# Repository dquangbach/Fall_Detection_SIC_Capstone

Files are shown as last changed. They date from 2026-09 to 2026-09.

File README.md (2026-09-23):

# Fall Detection — CNN-LSTM & Leave-One-Subject-Out

Dự án phát hiện té ngã từ gia tốc ba trục, sử dụng **CNN-LSTM** và đánh giá khả năng tổng quát hóa sang người chưa xuất hiện trong tập train bằng **Leave-One-Subject-Out (LOSO)** trên **32 subject K-Fall**.

Pipeline chính nằm trong [model_cnn_lstm_loso.ipynb](model_cnn_lstm_loso.ipynb): đọc nhãn K-Fall, tạo cửa sổ, huấn luyện và đánh giá 32 fold, sau đó train model cuối trên dữ liệu của cả 32 subject. [model_cnn_lstm.ipynb](model_cnn_lstm.ipynb) là thử nghiệm đối chứng với split cố định và **không augmentation**; không phải nguồn kết quả LOSO.

Repository còn có thiết kế PCB, phần firmware ESP32-S3/MPU6050 và receiver Polar H10 phục vụ thử nghiệm. Model CNN-LSTM Keras hiện tại và model nhúng trong firmware là các bộ artifact khác nhau.

## Cấu trúc dự án

```text
.
├── model_cnn_lstm_loso.ipynb     # Pipeline chính: LOSO + train model cuối
├── model_cnn_lstm.ipynb          # Đối chứng: split subject cố định, no augmentation
├── saved_models_cnn_lstm/
│   ├── best_model_SAxx.keras    # Checkpoint của fold có SAxx làm test
│   ├── final_selection_best.keras
│   ├── final_model.keras       # Model train lại trên toàn bộ 32 subject
│   ├── scaler.pkl              # Scaler đi cùng final_model.keras
│   ├── metadata.pkl            # Features, window, threshold, thông tin train cuối
│   ├── best_model_noaug.keras  # Checkpoint thử nghiệm no augmentation
│   └── best_model.keras        # Checkpoint thử nghiệm trước đó
├── kfall/
│   ├── label_data_new/         # Nhãn onset/impact: SAxx_label.xlsx
│   └── sensor_data_new/        # CSV theo subject, chuẩn bị riêng ở máy local
├── polar_h10_receiver/         # Thử nghiệm inference Python từ UDP Polar H10
├── esp32s3-tinyml-fall-detector/ # Repository firmware được ghi nhận bằng gitlink
├── fall_detection_pcb/         # Schematic, PCB, footprint KiCad và PDF
├── fall_detection_dataset/     # Dữ liệu local của pipeline cũ
└── doc/                        # Tài liệu tham khảo local
```

Các notebook cũ như `model.ipynb` và `model_3_features.ipynb` không còn trong cây dự án hiện tại. Bắt đầu với **`model_cnn_lstm_loso.ipynb`**.

## Dữ liệu và nhãn

Notebook chính đọc trực tiếp:

```text
kfall/
├── label_data_new/
│   ├── SA06_label.xlsx
│   └── ...
└── sensor_data_new/
    ├── SA06/
    │   ├── S06T01R01.csv
    │   └── ...
    └── ...
```

- Danh sách subject được lấy từ các thư mục bắt đầu bằng `SA` trong `sensor_data_new`.
- Tên CSV theo mẫu `SxxTxxRxx.csv`, chứa subject, task và trial.
- CSV cần các cột `FrameCounter`, `AccX`, `AccY`, `AccZ`. Dữ liệu được dùng theo thứ tự dòng có sẵn trong file; cần giữ thứ tự thời gian.
- File Excel nhãn sử dụng `Task Code (Task ID)`, `Trial ID`, `Fall_onset_frame`, `Fall_impact_frame`.
- Nhãn mẫu là ngã nếu `onset <= FrameCounter <= impact`. Recording không có trong bảng nhãn được xem là bình thường; cần chuẩn bị đầy đủ các file nhãn để tránh gán sai.
- Pipeline này không cần cột `FallCheck` và không đọc từ `Sample_Training/Sample_Test` của pipeline cũ.

Dữ liệu gia tốc dùng đơn vị **g**, với bước thời gian 0.01 giây (100 Hz) trong CSV K-Fall hiện có. Notebook không tự resample hoặc chuyển đơn vị.

### Cửa sổ và chuẩn hóa

| Thiết lập | Giá trị |
|---|---|
| Features theo thứ tự | `AccX, AccY, AccZ` |
| Window size | 200 mẫu, khoảng 2 giây ở 100 Hz |
| Window step | 100 mẫu, overlap 50% |
| Nhãn cửa sổ | Fall nếu ít nhất 20% mẫu nằm trong khoảng onset–impact |
| Input model | `(batch, 200, 3)`, không flatten |
| Output | Một sigmoid score cho lớp Fall |
| Decision threshold | `score >= 0.50` → Fall |

Cửa sổ được tạo riêng trong từng recording; không nối hai recording hoặc hai subject. Đoạn cuối thiếu 200 mẫu bị bỏ qua. Cửa sổ từng subject được cache trong RAM để tái sử dụng qua các fold.

Trong mỗi fold, `StandardScaler` được fit **chỉ trên cửa sổ train gốc**, theo từng feature bằng `reshape(-1, 3)`. Scaler đó transform train, train augmentation, validation và test. Không fit scaler trên subject test.

### Augmentation của pipeline chính

Chỉ áp dụng lên tập train, trước chuẩn hóa:

| Phép biến đổi | Xác suất trên mỗi bản sao cửa sổ | Cấu hình |
|---|---:|---|
| Jitter | 0.10 | Nhiễu Gaussian, mean 0, sigma 0.05 |
| Scaling | 0.10 | Một hệ số chung cho Acc XYZ, Gaussian mean 1, sigma 0.10 |
| Rotation | 0.10 | Góc ngẫu nhiên ±10° mỗi trục, cùng phép quay cho toàn bộ cửa sổ |

Ba phép được chọn độc lập nên một cửa sổ có thể nhận nhiều phép hoặc không nhận phép nào. Ghép tập gốc với tập bản sao để tăng gấp đôi số window train; nhãn giữ nguyên. Validation/test của LOSO không augmentation.

## Kiến trúc CNN-LSTM

```text
Input (200, 3)
  → Conv1D(32, kernel=5, same) → BatchNorm → ReLU → MaxPool(2) → Dropout(0.2)
  → Conv1D(64, kernel=3, same) → BatchNorm → ReLU → MaxPool(2) → Dropout(0.2)
  → LSTM(64, dropout=0.2, recurrent_dropout=0)
  → Dense(32, ReLU) → Dropout(0.3)
  → Dense(1, sigmoid)
```

CNN trích đặc trưng cục bộ theo thời gian; LSTM xử lý chuỗi đặc trưng sau hai bước pooling. Loss là `binary_crossentropy`; optimizer Adam bắt đầu tại learning rate `1e-3`. Class weight được tính theo `N / (2 × N_class)` để cân bằng hai lớp.

## Đánh giá Leave-One-Subject-Out

Với 32 subject, notebook chạy 32 fold. Trong mỗi fold:

1. Giữ 1 subject làm **test độc lập**.
2. Chọn xoay vòng 2 subject trong 31 subject còn lại làm validation.
3. Dùng 29 subject còn lại để train, augmentation và fit scaler.
4. Khởi tạo CNN-LSTM mới, chọn checkpoint theo validation.
5. Nạp checkpoint tốt nhất và dự đoán subject test tại threshold cố định 0.50.

Mỗi subject làm test đúng một lần. Đây là LOSO có validation tách theo subject, không phải chia ngẫu nhiên window và cũng không phải nested LOSO để tìm hyperparameter.

### Cấu hình huấn luyện mỗi fold

| Thiết lập | Giá trị trong code |
|---|---|
| Batch size | 32 |
| Epoch tối đa | 50 |
| ModelCheckpoint | `val_recall`, `mode="max"`, lưu best |
| EarlyStopping | `val_recall`, patience 12, min_delta `1e-3`, restore best weights |
| ReduceLROnPlateau | `val_loss`, patience 3, factor 0.5, min_lr `1e-5` |
| Threshold test | 0.50, không quét ngưỡng trên test |

Checkpoint lưu thành `saved_models_cnn_lstm/best_model_<test_subject>.keras`. Test dùng checkpoint tải lại; `ModelCheckpoint` không đặt `min_delta` như `EarlyStopping`, nên hai callback có thể chọn epoch khác nhau.

### Báo cáo kết quả

Cell tổng hợp tạo:

- Bảng mỗi fold: số window, phân bố lớp, Accuracy, Precision/Recall/F1/F2 lớp Fall, ROC-AUC và TN/FP/FN/TP.
- Mean, standard deviation, min và max qua các fold. ROC-AUC là NaN nếu test fold chỉ có một lớp.
- Confusion matrix và classification report gộp dự đoán của toàn bộ subject test.
- Biểu đồ Precision và Recall theo subject.

Mean qua subject và metrics gộp theo window là hai cách tổng hợp khác nhau. Các chỉ số ở đây đánh giá **cửa sổ**, không tự tương đương số sự kiện ngã phát hiện được hoặc số cảnh báo giả mỗi giờ.

**Tình trạng kết quả trong repository:** có 32 checkpoint theo subject, nhưng notebook LOSO hiện lưu với output rỗng và chưa có bảng metrics LOSO được export. Vì vậy README không gán số đo từ notebook đối chứng hay validation của model cuối cho LOSO. Để công bố kết quả, lưu output cell tổng hợp và bảng từng fold sau lần chạy tương ứng.

Scalers từng fold và dự đoán test chưa được lưu thành artifact riêng. Cell mục 7 có thể nạp trực tiếp 32 file `best_model_SAxx.keras` và dựng lại scaler từ đúng 29 subject train gốc của mỗi fold, không cần train lại model. Việc này yêu cầu giữ nguyên dataset, nhãn, thứ tự subject, features, window và cách chia fold như khi train checkpoint. `scaler.pkl` hiện có thuộc model cuối; không dùng scaler này để đánh giá checkpoint LOSO.

## Train model cuối trên 32 subject

Cell cuối của notebook chính dùng `FINAL_USE_AUGMENTATION = True`, seed 42 và thực hiện hai pha:

1. **Chọn epoch:** ghép dữ liệu 32 subject, fit scaler trên toàn bộ window gốc, tạo augmentation, chuẩn hóa và shuffle. Giữ 10% window bằng `validation_split=0.10`; train tối đa 100 epoch, với checkpoint/early stopping theo `val_recall` (patience 12) và giảm LR theo `val_loss` (patience 3). Chọn `argmax(val_recall) + 1`.
2. **Train lại toàn bộ:** khởi tạo CNN-LSTM mới và train trên tất cả window gốc + augmentation của 32 subject đến epoch vừa chọn. Pha này không giữ validation, không dùng early stopping hoặc ReduceLROnPlateau; Adam bắt đầu lại tại `1e-3`. Lưu thành `final_model.keras`.

Validation pha 1 là split theo window sau khi augmentation và fit scaler toàn bộ; các window overlap hoặc bản gốc/bản sao có thể nằm hai phía của split. Vì vậy nó chỉ là tín hiệu chọn epoch nội bộ, **không phải đánh giá subject độc lập**. Lịch giảm LR ở pha 1 cũng không được phát lại trong pha train toàn bộ. Chất lượng cần được báo cáo bằng protocol đánh giá phù hợp, không bằng training score của model cuối.

File `metadata.pkl` hiện ghi: **32 subject, augmentation bật, selected_epoch = 13**, `selected_val_recall ≈ 0.996633`. Đây là thông tin pha chọn epoch của lần export, không phải Recall LOSO hay kết quả kiểm thử độc lập của `final_model.keras`.

### Bộ artifact để inference

| File trong `saved_models_cnn_lstm/` | Vai trò |
|---|---|
| `final_model.keras` | CNN-LSTM train lại trên toàn bộ dữ liệu |
| `scaler.pkl` | StandardScaler fit trên window gốc của 32 subject |
| `metadata.pkl` | Feature order, window size/step, threshold, subject và cấu hình train cuối |
| `final_selection_best.keras` | Checkpoint pha chọn epoch; không phải model train lại toàn bộ |
| `best_model_SAxx.keras` | Model fold LOSO có subject SAxx làm test |
| `best_model_noaug.keras` | Checkpoint thử nghiệm đối chứng no augmentation |

Luôn sử dụng `final_model.keras`, `scaler.pkl` và `metadata.pkl` từ cùng lần export. Khi inference, chỉ transform bằng scaler đã lưu; không fit lại scaler, không augmentation.

## Cài đặt và chạy

Từ thư mục gốc repository:

```bash
python3 -m venv .venv
source .venv/bin/activate
python -m pip install tensorflow numpy pandas scikit-learn matplotlib joblib openpyxl jupyterlab
python -m jupyter lab
```

Trên Windows, kích hoạt bằng `.venv\Scripts\activate`. Chưa có file khóa dependency Python trong repository; cần lưu phiên bản môi trường cho các lần chạy cần tái lập.

1. Chuẩn bị đầy đủ CSV và Excel nhãn theo cấu trúc `kfall/` ở trên.
2. Mở `model_cnn_lstm_loso.ipynb`, chọn kernel đúng môi trường, chạy với working directory là gốc repository.
3. Chạy các cell import, đọc nhãn, cấu hình, cache dữ liệu, augmentation và định nghĩa model.
4. Nếu đã có 32 checkpoint, chạy thẳng **mục 7** để nạp model và đánh giá; chỉ cần import và các mục 1–3, bỏ qua mục 6. Nếu cần train lại, chạy mục 6 trước. Lưu notebook cùng output khi cần báo cáo.
5. Sau khi chốt cách đánh giá, chạy cell cuối để tạo model cho toàn bộ 32 subject.

Nếu chỉ cần train model cuối sau khi đã hoàn tất LOSO, có thể chạy các cell chuẩn bị ở bước 3 rồi chuyển thẳng đến cell cuối; không bắt buộc chạy lại 32 fold. Chạy lại sẽ ghi đè các artifact cùng tên trong `saved_models_cnn_lstm/`; sao lưu bộ cần giữ trước khi thực hiện.

LOSO hiện không đặt seed riêng cho từng fold, trong khi cell final đặt seed 42. Các lần chạy LOSO có thể khác nhau do khởi tạo trọng số, dropout và augmentation ngẫu nhiên.

### Notebook đối chứng

`model_cnn_lstm.ipynb` giữ 6 subject test cố định:
`SA21, SA23, SA24, SA26, SA30, SA33`; chia 26 subject còn lại thành 21 train và 5 validation. Cấu hình hiện tại không augmentation, tối đa 100 epoch, early stopping patience 12 và LR patience 3. Kết quả của notebook này phục vụ đối chiếu, không thay thế đánh giá LOSO.

## Thử nghiệm trực tiếp với Polar H10

Khi có thư mục `polar_h10_receiver/`, chạy trong môi trường đã cài dependencies:

```bash
python polar_h10_receiver/udp_acc_receiver.py --check-model
python polar_h10_receiver/udp_acc_receiver.py
```

Sender gửi UDP đến IP máy tính, port **5005**, theo `timestamp,x_mg,y_mg,z_mg`, với tốc độ đã cấu hình **100 mẫu/giây**. Receiver:

- Đổi mg → g và đổi trục thành `(Polar Y, -Polar X, -Polar Z)`.
- Gom window 200 mẫu, dự đoán lại mỗi 100 mẫu, dùng bộ artifact final.
- In sigmoid score và nhãn tại threshold trong metadata.
- Bỏ mẫu lỗi/trùng/đảo timestamp; reset sau 2 giây không nhận mẫu hợp lệ.

Mặc định đếm frame ở 100 Hz, không resample. Khi biết đơn vị timestamp, có thể thêm `--timestamp-unit ns` (hoặc `us/ms`) để kiểm tra nhịp lấy mẫu và khoảng mất mẫu. Thêm `--show-acc` để xem gia tốc.

Mapping trục giữ từ thử nghiệm receiver; hướng gắn cảm biến, dấu trục Z và khác biệt vị trí đo so với K-Fall cần được xác nhận thực nghiệm. Kết quả LOSO trên K-Fall không tự đại diện cho chất lượng nhận diện trực tiếp trên Polar.

## Phần cứng và trạng thái triển khai

- `fall_detection_pcb/`: thiết kế KiCad, schematic, PCB, footprint ESP32-S3/header và các PDF lớp mạch.
- `esp32s3-tinyml-fall-detector/`: phần firmware ESP32-S3 + MPU6050, lấy mẫu, preprocessing, TFLite Micro, LED và Wi-Fi/MQTT.

Firmware đang là repository riêng, được repository này tham chiếu bằng gitlink; hiện chưa có `.gitmodules` để tự khởi tạo bằng `git submodule update`. Khi clone mới, cần lấy firmware từ repository riêng và đối chiếu revision được ghi nhận.

Bản firmware local đang có thay đổi chưa commit cho input INT8 6 features `(200 × 6)`, step 50; revision firmware được repository chính tham chiếu vẫn dùng cấu hình 8 features. Cả hai đều khác bộ CNN-LSTM final với input float32 `(1,200,3)`. Chưa có artifact TFLite/C của CNN-LSTM final trong `saved_models_cnn_lstm/`; cần thực hiện export, đồng bộ preprocessing và kiểm tra runtime trước khi triển khai model này lên ESP32-S3.

## Dữ liệu và quản lý repository

CSV và file H5 bị loại theo `.gitignore`; thư mục sensor K-Fall cần chuẩn bị riêng khi clone. Các Excel nhãn K-Fall và bộ checkpoint Keras hiện được Git theo dõi. `doc/`, môi trường ảo và cache Python là dữ liệu local.

Thêm một thư mục vào `.gitignore` không tự bỏ tracking các file đã commit. Receiver Polar hiện vẫn có file được Git theo dõi; cần phân biệt tình trạng đó với quy tắc ignore local.

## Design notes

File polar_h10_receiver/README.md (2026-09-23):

# Polar H10 → CNN-LSTM trực tiếp

Chạy từ thư mục `Fall_Detection_SIC_Capstone`, bằng môi trường Python đã dùng train:

```sh
../.venv/bin/python polar_h10_receiver/udp_acc_receiver.py
```

Sender gửi UDP đến IP máy tính, port **5005**, mỗi mẫu theo định dạng
`timestamp,x_mg,y_mg,z_mg`. Một datagram có thể chứa nhiều dòng mẫu.
Timestamp phải tăng theo từng mẫu cảm biến; không dùng chung timestamp của một
batch cho tất cả mẫu. Sender nên giữ cùng socket/cổng nguồn trong phiên streaming.

Receiver mặc định dùng **100 frame/giây** theo cấu hình Polar được xác nhận.
Nó tự đọc `final_model.keras`, `scaler.pkl`, `metadata.pkl` trong
`saved_models_cnn_lstm/` (đường dẫn tính từ file script, không phụ thuộc cwd).
Các thư viện cần có trong môi trường: TensorFlow, NumPy, scikit-learn, joblib.

Pipeline: đổi mg → g → đổi trục `(X,Y,Z) = (Polar Y,-Polar X,-Polar Z)` →
gom 200 mẫu → transform bằng scaler đã xuất → tensor `(1,200,3)` → model.
Không fit lại scaler và không augmentation khi dự đoán. `window_size`, `window_step`,
thứ tự feature và threshold lấy từ metadata; hiện là **200 / 100 / 0.50**.
Lần đầu cần khoảng 2 giây dữ liệu, sau đó dự đoán mỗi giây.

Ví dụ định dạng kết quả (số minh họa):

```text
t=123456789 | FALL / NGA | P(fall)=0.8732 | inference=4.5ms
```

Các tùy chọn:

```sh
# Kiểm tra bộ artifact và warm-up inference, không mở UDP
../.venv/bin/python polar_h10_receiver/udp_acc_receiver.py --check-model

# In thêm gia tốc từng mẫu
../.venv/bin/python polar_h10_receiver/udp_acc_receiver.py --show-acc

# Khi đã xác nhận timestamp đơn vị ns (hoặc ms/us), bật kiểm tra gap/cadence
../.venv/bin/python polar_h10_receiver/udp_acc_receiver.py --timestamp-unit ns

# Ghi lại stdout của phiên thử nghiệm
../.venv/bin/python -u polar_h10_receiver/udp_acc_receiver.py | tee polar_session.log
```

Nhấn Ctrl+C để dừng. Mẫu lỗi, timestamp trùng hoặc đảo thứ tự bị bỏ qua. Sau 2 giây
không có mẫu hợp lệ, buffer và sender được reset. Mặc định chưa biết đơn vị timestamp
nên không phát hiện được mọi khoảng mất gói ngắn; dùng `--timestamp-unit` khi đã xác
nhận để reset nếu khoảng cách mẫu lệch quá 20% so với 0.01 giây. Code không resample;
sender phải thực sự chạy 100 Hz. `--timeout` cho phép đổi thời gian reset.

Phép đổi trục được giữ từ receiver cũ, trong đó dấu trục Z còn cần kiểm chứng thực
nghiệm. Vị trí đeo H10 và hướng trục so với cảm biến K-Fall có thể ảnh hưởng kết quả;
metrics LOSO K-Fall không phải kết quả kiểm chứng trên Polar trực tiếp.

Kiểm tra parser, cửa sổ, gap và inference với model thật:

```sh
../.venv/bin/python -m unittest discover -s polar_h10_receiver -v
```

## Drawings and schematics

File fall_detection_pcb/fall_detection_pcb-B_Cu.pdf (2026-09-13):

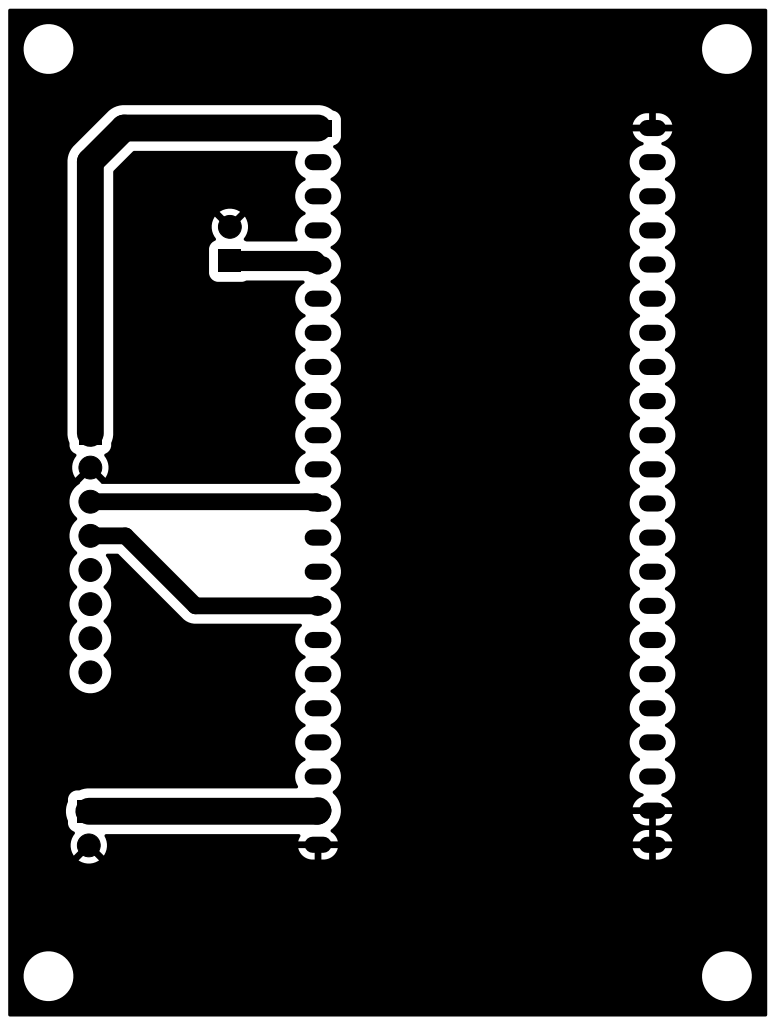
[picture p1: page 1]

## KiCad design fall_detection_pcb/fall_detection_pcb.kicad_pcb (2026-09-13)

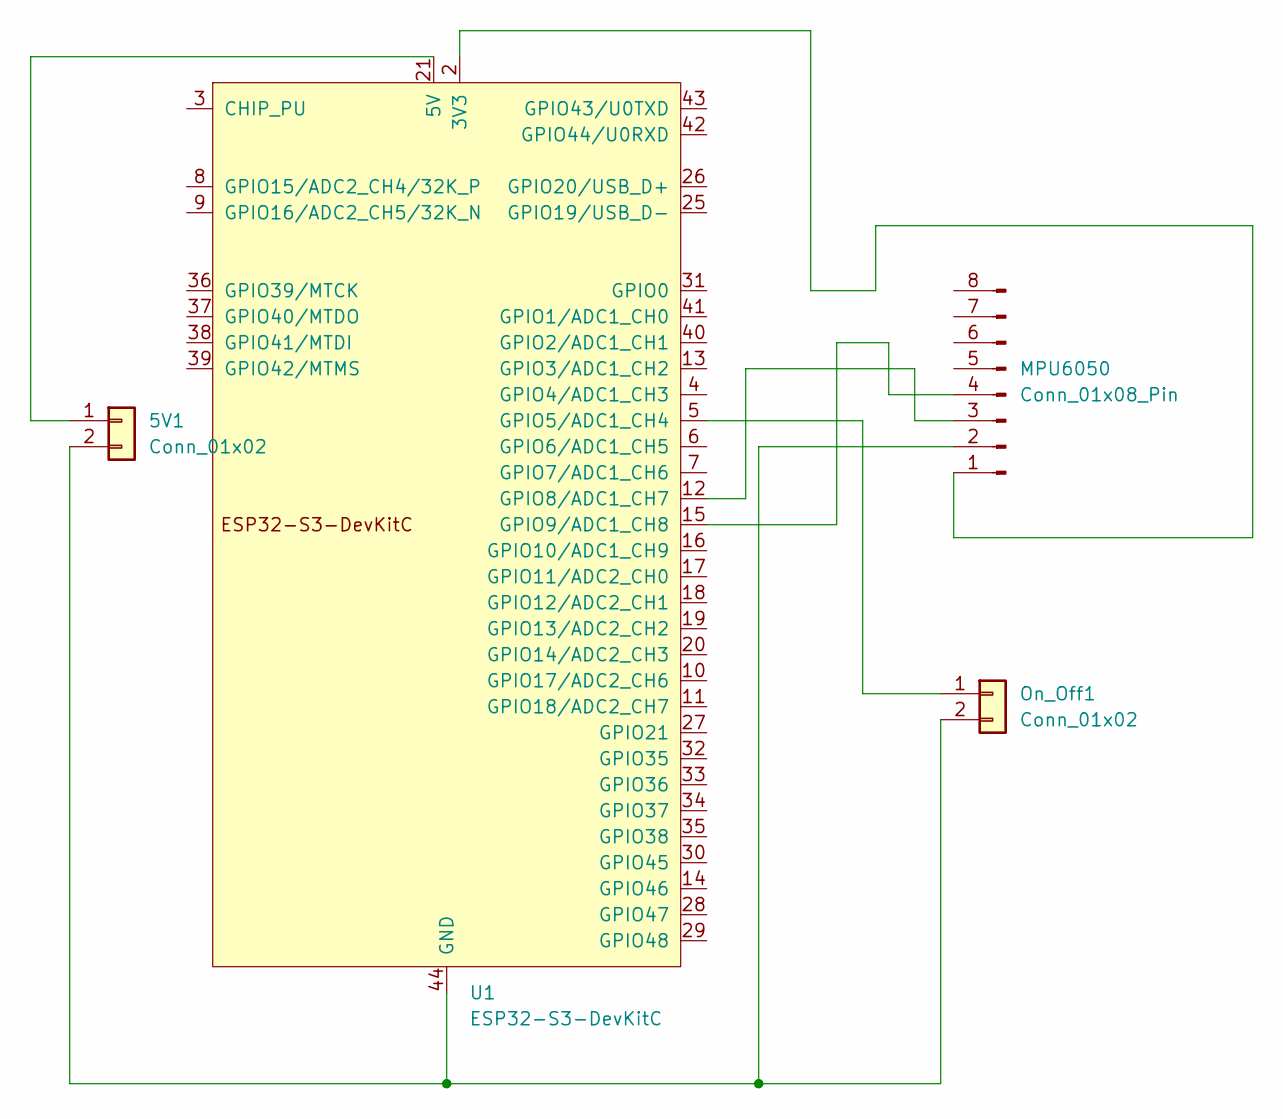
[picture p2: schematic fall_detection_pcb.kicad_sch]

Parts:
5V1: Conn_01x02; PinHeader_1x02_P2.54mm_Vertical
MPU6050: Conn_01x08_Pin; PinHeader_1x08_P2.54mm_Horizontal
On_Off1: Conn_01x02; PinHeader_1x02_P2.54mm_Vertical
U1: ESP32-S3-DevKitC

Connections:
unnamed: 5V1.1, U1.21 (5V)
unnamed: 5V1.2, MPU6050.2, On_Off1.2, U1.22 (GND), U1.23 (GND), U1.24 (GND), U1.44 (GND)
unnamed: MPU6050.1, U1.1 (3V3), U1.2 (3V3)
unnamed: MPU6050.3, U1.12 (GPIO8/ADC1_CH7)
unnamed: MPU6050.4, U1.15 (GPIO9/ADC1_CH8)
unnamed: On_Off1.1, U1.5 (GPIO5/ADC1_CH4)

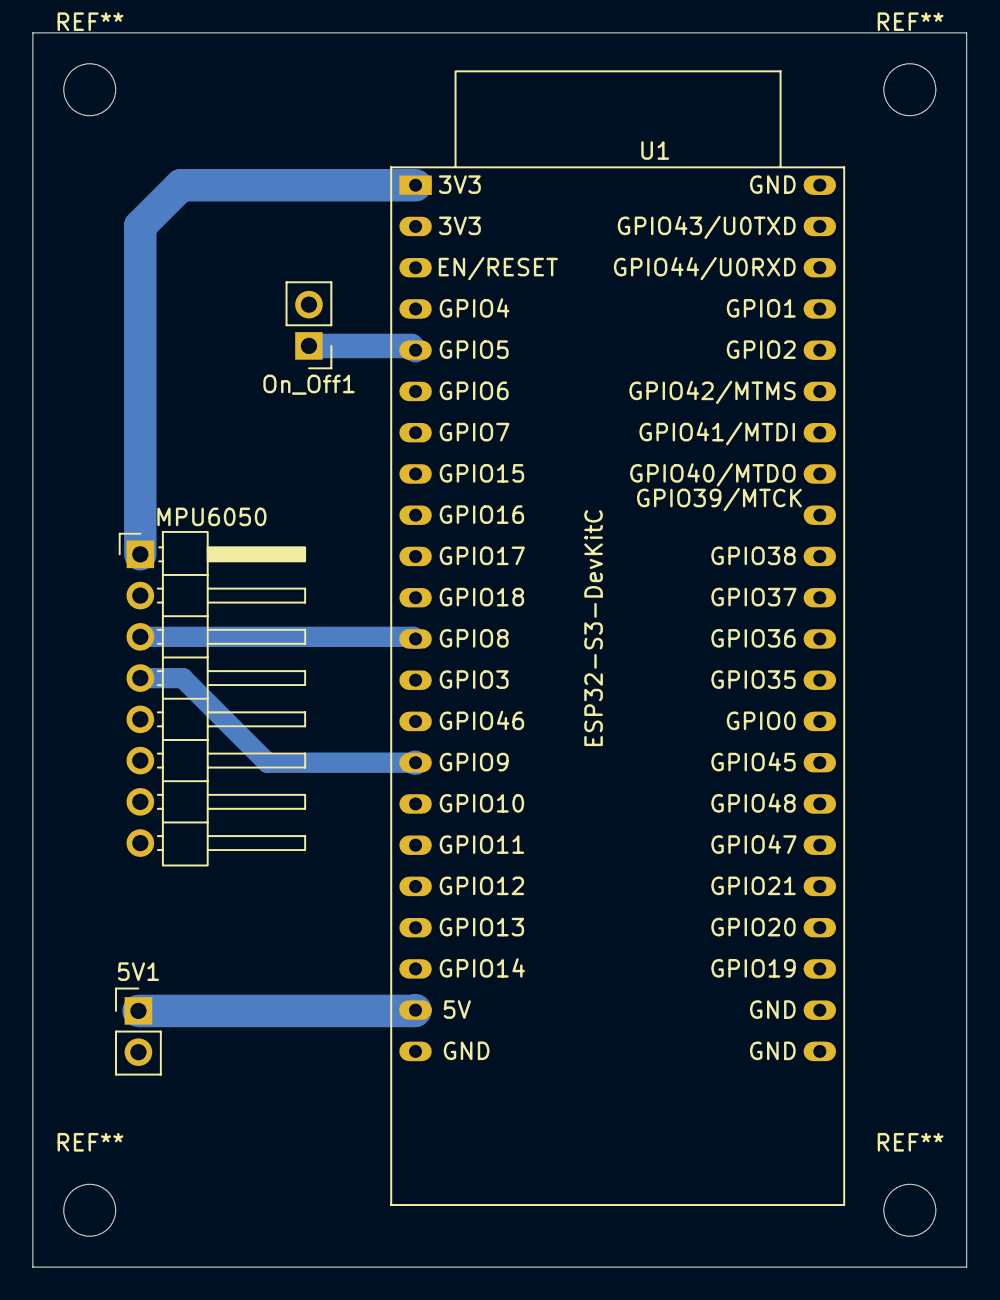
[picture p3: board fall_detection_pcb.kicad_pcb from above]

Board: 2 copper layers, 57.5 x 76.0 mm, 4 parts (0 on the bottom side), 6 nets.

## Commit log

2026-09-05 Testing all folders in Sample_Test
2026-09-13 int8 quantize
    [fall_detection_pcb.kicad_pcb, fall_detection_pcb.kicad_sch]
2026-09-16 Add 6-feature fall detection model and INT8 export
    [int8_test_metrics.csv, int8_validation_threshold_metrics.csv, test_metrics.csv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]
2026-09-23 CNN_LSTM experiment
    [SA06_label.xlsx, SA07_label.xlsx, SA08_label.xlsx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]
